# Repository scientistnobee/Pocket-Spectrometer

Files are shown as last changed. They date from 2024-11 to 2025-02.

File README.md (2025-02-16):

# Pocket Spectrometer

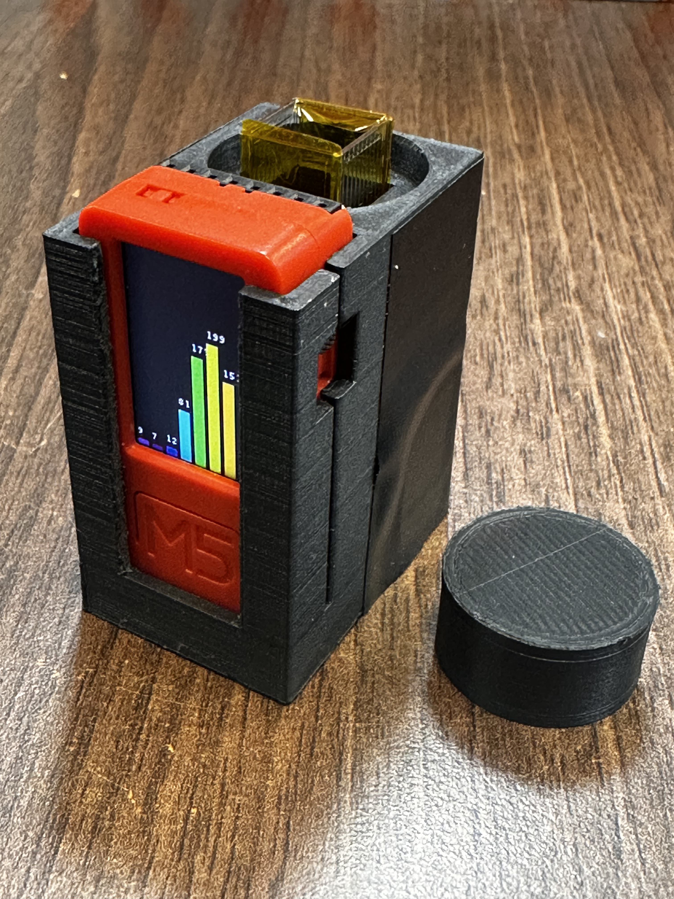
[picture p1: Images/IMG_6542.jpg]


## The Vision

I've always wanted to create a spectrometer that is so small it can fit into one's pocket and just barely larger than a cuvette itself. Working with bulky commercial spectrometers in labs, I was wondering about applications of such a small spectrometer. That's when I discovered the perfect combination – the M5StickC microcontroller and the AS7341 spectral sensor. My goal was simple: create an ultra-compact spectrometer that anyone could use.

## Why This Matters

While commercial spectrometers offer high precision, they're often expensive, bulky, and require a computer connection. I wanted something different – a standalone device that could fit in your pocket, complete with its own display and interface, without requiring external equipment such as connection to a mobile app or a computer. The kind of tool that could democratize spectroscopy for educators, students, and citizen scientists.

## Bill of Materials (BOM)

* 1x M5StickC (https://docs.m5stack.com/en/core/m5stickc_plus) 
* 1x AS7341 spectral sensor  (https://www.dfrobot.com/product-2132.html)
* 1x Grove connector  (https://docs.m5stack.com/en/accessory/cable/grove_cable)
* 2x M2 screws  (https://eu.mouser.com/ProductDetail/Harwin/M80-2260000B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)
* 2x M2 heat-set inserts  (https://www.mouser.com/ProductDetail/SI/IUTFB-M2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)
* Black filament for 3D printing  
* White reflector (Optional)

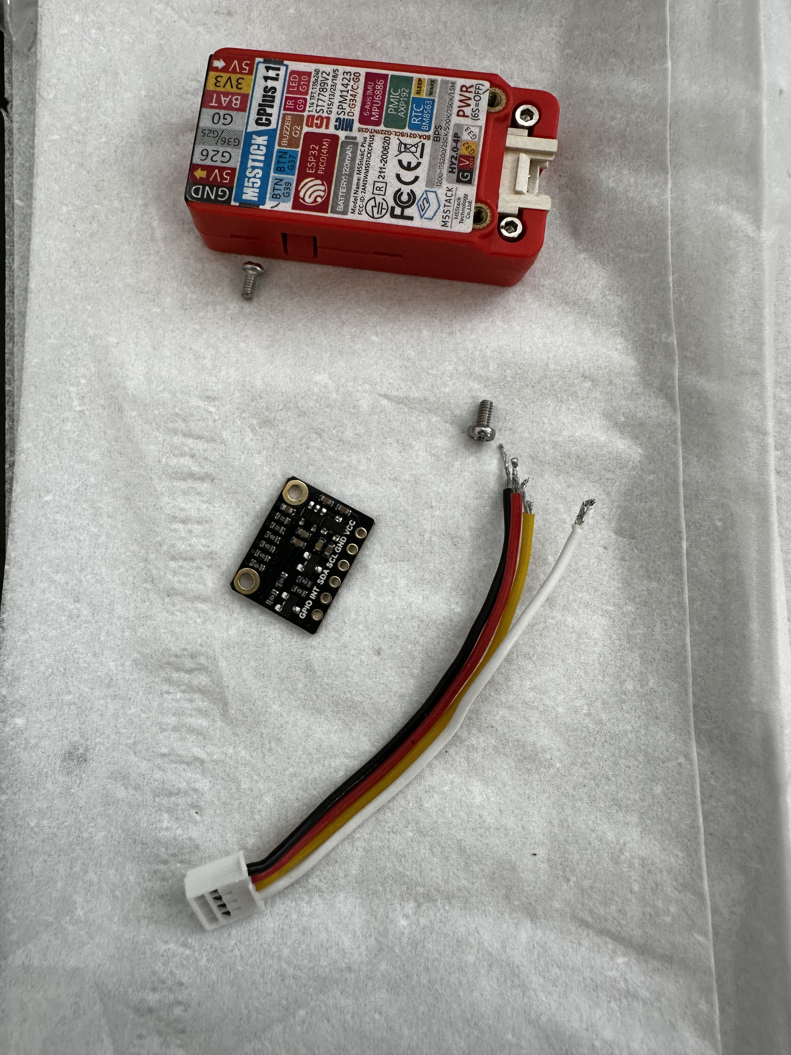
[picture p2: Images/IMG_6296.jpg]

## 3D-Printed Components

* Main body
* Cap

## Hardware Tools Required

* 3D printer  
* Soldering iron  
* Screwdriver

## Software Tools Required

* OpenSCAD for 3D printed parts (Optional, only required to modify the designs)  
* 3D printer slicer software (I used Ultimaker’s CURA)  
* Thonny IDE for programming

## Reasoning for choosing the particular Electronic Components

### AS7341 Spectral sensor: Advanced Spectral Sensing

The AS7341 sensor is crucial for this project:

* 11 readable individual sensor elements (10 light channels plus flicker detection)  
* Coverage from 350-1000 nm for comprehensive analysis  
* Built-in LED control for consistent illumination  
* Low power consumption for extended battery life  
* Affordable price point (\~$16)

### M5StickC: Portable but powerful mini computer

The M5StickC is the perfect platform for this project because it packs incredible functionality into a tiny package:

- Built-in rechargeable battery for true portability and for on-field applications  
- USB-C connector for easy charging and programming  
- Seeed Grove port for simple sensor connections  
- Two user-programmable buttons for interface control  
- TFT display screen for displaying spectra in real-time   
- Beautifully labeled breakout header for expansion  
- Extra in-bulit sensors (6-axis IMU, Microphone, IR transmitter)   
- Compact size (48.2 x 25.5 x 13.7mm) ideal for portable size of pocket spectrometer  
- MicroPython support for easy programming  
- Affordable price point (\~$20)

## Build Instructions

### Hardware Assembly

1. Cut the Grove connector to 15cm length and solder the wires  

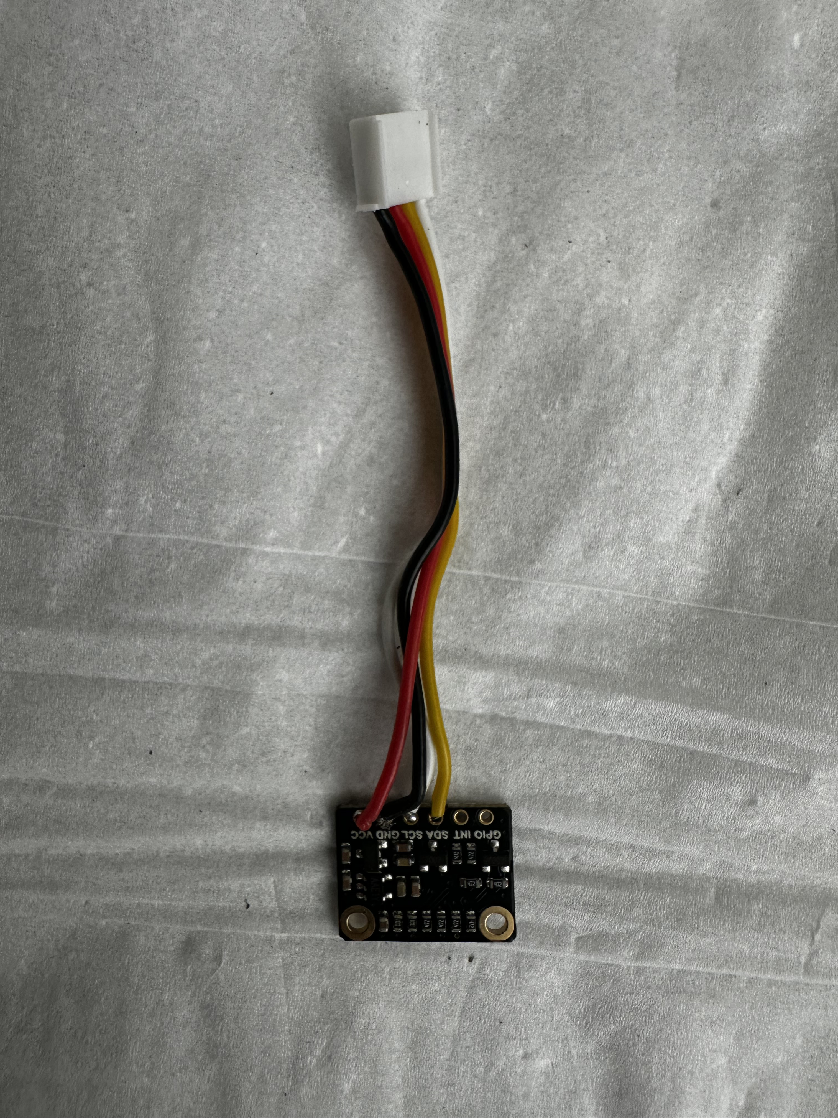
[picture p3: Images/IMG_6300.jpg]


3. Connect the Grove cable to the M5StickC  
4. Flash the firmware using Thonny  
5. Test the spectral sensor functionality  
6. Disconnect the Grove connector  
7. 3D print the main body and cap (no support required)  
8. Install M2 heat-set inserts using the soldering iron
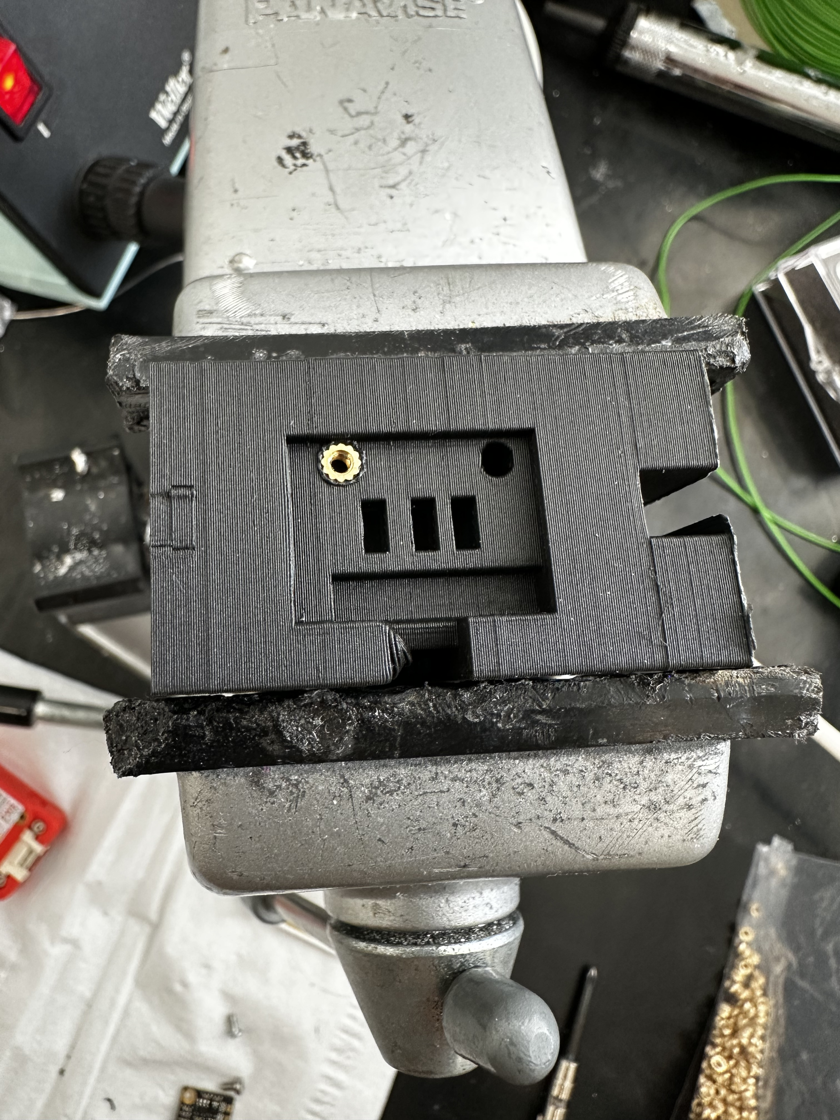
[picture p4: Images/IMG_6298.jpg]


9. Mount the AMS sensor to the body using M2 screws  
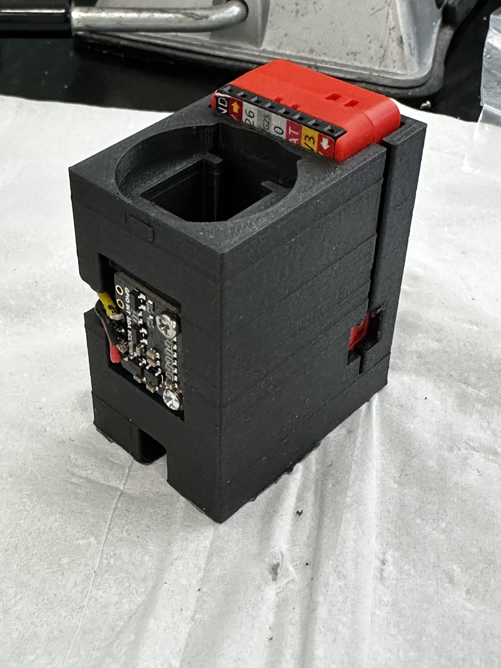
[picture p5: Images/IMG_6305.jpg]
    

10. Press-fit the M5StickC into the body from the top  
11. Connect the Grove connector from the bottom  
12. Apply black tape to cover the AMS sensor and wires


## Firmware Setup Instructions

### 1\. Prepare M5StickC

1. Power on the M5StickC  
2. Quickly press the M5 button after restart (using reset/PWR button) until you see the settings screen  
3. Select "Switch Mode" using the M5 button  
4. Choose "USB Mode" from the options

### 2\. Set Up Thonny IDE

1. Download and install [Thonny IDE](https://thonny.org/)  
2. Open Thonny  
3. Navigate to Tools \> Options \> Interpreter  
4. Configure settings:  
   - Set interpreter to "MicroPython (ESP32)"  
   - Select the correct COM port for your M5StickC  
   - Click OK and reconnect  
5. Once connected, you can write and test code directly in the IDE  
6. Best practice is to write your code in `main.py` for automatic execution on startup  

## Applications

The Pocket Spectrometer has numerous practical applications:

### Environmental Monitoring

* **Water Quality Testing**:  
  - Measure water turbidity  
  - Test chlorine content  
  - Monitor pH levels  
  - Assess water hardness  
  - Analyze phosphate content

### Biological Applications

* **Aquatic Habitat Monitoring**:  
  - Track ammonia levels  
  - Measure nitrate and nitrite concentrations  
  - Monitor phosphate levels  
  - Ideal for both freshwater and saltwater systems  
  - Perfect for aquaponics monitoring

### Environmental Testing

* **Soil Analysis**:  
  - Detect environmental pollutants  
  - Measure heavy metals like lead  
  - Test for oil contamination  
  - Monitor diesel presence  
  - Screen for pesticides

### Laboratory Use

* **Biochemical Analysis**:  
  - Protein quantification using Bradford assay  
  - Colorimetric enzyme assays  
  - Chemical concentration measurements  
  - Educational demonstrations  
  - STEM project applications

## Technical Implementation

The code is written in MicroPython for simplicity and accessibility, making it easy to modify for various applications. Most of the AI tools nowadays are good with python code, so would be handy to have the code in micropython.

## Future Work

* Upgrade to AS7343 as it has 14 spectral channels, compared to 10 spectral channels of  AS7341  
* Optimize battery life for extended field use  
* Conduct comprehensive testing (Work in progress)  
* Write the protocols in detail and make standard curve plots  
* Add saving the spectra as a time-stamped text file 

## Troubleshooting Tips for software

* If code doesn't execute properly, use the stop/rerun button in Thonny until you see three forward-looking arrows in the console  
* Restart the device if experiencing connection issues  
* Ensure proper USB mode selection before programming  
* Double-check Grove connector wiring if sensor readings are incorrect

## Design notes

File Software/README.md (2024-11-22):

# micropython-as7341

@Chinna Devarapu
- Adapted for M5StickC using bottom I2C sensor port
- Added LED control support for DF Robots AS7341 sensor
- Added example for saving spectral data as text (save_data.py)
- Main functionality in main.py: displays spectral data as bar graph with count values above bars
- Developed using Thonny IDE

Original MicroPython driver by Rob Hamerling (Version 0.0, September 2022)
- Class for AS7341: 11 Channel Multi-Spectral Digital Sensor
- Adapted from WaveShare's Raspberry Pi implementation
- Source: https://www.waveshare.com/w/upload/b/b3/AS7341_Spectral_Color_Sensor_code.7z

## Modifications from Original
- Required specification of active I2C interface
- Pythonized implementation
- Optimized function names and I2C communications
- Improved code readability
- Added documentation strings

## Getting Started
- Use Micropython device with hardware I2C (e.g. ESP32)
- Connect AS7341 board via I2C interface
- Copy required files:
  - as7341.py
  - as7341_smux_select.py
- For GPIO examples: Connect GPIO pin to +3.3V (10K resistor) and pushbutton to GND

## Examples
- all_channels.py: read whole range of channels
- flicker.py: read flicker
- gpio_in_en.py: show use of GPIO pin for input
- interrupt.py: use of interrupt pin
- led_blink_pwm: show control of onboard LED
- pinint.py: use pin to trigger read-out
- syns.py: syns-mode, measurement starts with GPIO transition

## Documentation
- AS7341_AN000666_1-01.pdf - Application Note: SMUX Configuration
- AS7341_DS000504_3-00.pdf - Datasheet: 11-Channel Multi-Spectral Digital Sensor

Note: Repository is work in progress.

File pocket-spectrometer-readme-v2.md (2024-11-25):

# Pocket Spectrometer Project

## The Vision

I've always wanted to create a spectrometer that is so small it can fit into one's pocket and just barely larger than a cuvette itself. Working with bulky commercial spectrometers in labs, I was wondering about applications of such a small spectrometer. That's when I discovered the perfect combination – the M5StickC microcontroller and the AS7341 spectral sensor. My goal was simple: create an ultra-compact spectrometer that anyone could use.

## Why This Matters

While commercial spectrometers offer high precision, they're often expensive, bulky, and require a computer connection. I wanted something different – a standalone device that could fit in your pocket, complete with its own display and interface, without requiring external equipment such as connection to a mobile app or a computer. The kind of tool that could democratize spectroscopy for educators, students, and citizen scientists.

## Bill of Materials (BOM)

* 1x M5StickC  
* 1x AS7341 spectral sensor  
* 1x Grove connector  
* 2x M2 screws  
* 2x M2 heat-set inserts  
* Black filament for 3D printing  
* White reflector (Optional)

## 3D-Printed Components

* Main body  
* Cap

## Hardware Tools Required

* 3D printer  
* Soldering iron  
* Screwdriver

## Software Tools Required

* OpenSCAD for 3D printed parts (Optional, only required to modify the designs)  
* 3D printer slicer software (I used Ultimaker’s CURA)  
* Thonny IDE for programming

## Reasoning for choosing the particular Electronic Components

### AS7341 Spectral sensor: Advanced Spectral Sensing

The AS7341 sensor is crucial for this project:

* 11 readable individual sensor elements (10 light channels plus flicker detection)  
* Coverage from 350-1000 nm for comprehensive analysis  
* Built-in LED control for consistent illumination  
* Low power consumption for extended battery life  
* Affordable price point (\~$16)

### M5StickC: Portable but powerful mini computer

The M5StickC is the perfect platform for this project because it packs incredible functionality into a tiny package:

- Built-in rechargeable battery for true portability and for on-field applications  
- USB-C connector for easy charging and programming  
- Seeed Grove port for simple sensor connections  
- Two user-programmable buttons for interface control  
- TFT display screen for displaying spectra in real-time   
- Beautifully labeled breakout header for expansion  
- Extra in-bulit sensors (6-axis IMU, Microphone, IR transmitter)   
- Compact size (48.2 x 25.5 x 13.7mm) ideal for portable size of pocket spectrometer  
- MicroPython support for easy programming  
- Affordable price point (\~$20)

## Build Instructions

### Hardware Assembly

1. Cut the Grove connector to 15cm length and solder the wires  
2. Connect the Grove cable to the M5StickC  
3. Flash the firmware using Thonny  
4. Test the spectral sensor functionality  
5. Disconnect the Grove connector  
6. 3D print the main body and cap (no support required)  
7. Install M2 heat-set inserts using the soldering iron  
8. Mount the AMS sensor to the body using M2 screws  
9. Press-fit the M5StickC into the body from the top  
10. Connect the Grove connector from the bottom  
11. Apply black tape to cover the AMS sensor and wires

## Firmware Setup Instructions

### 1\. Prepare M5StickC

1. Power on the M5StickC  
2. Quickly press the M5 button after restart (using reset/PWR button) until you see the settings screen  
3. Select "Switch Mode" using the M5 button  
4. Choose "USB Mode" from the options

### 2\. Set Up Thonny IDE

1. Download and install [Thonny IDE](https://thonny.org/)  
2. Open Thonny  
3. Navigate to Tools \> Options \> Interpreter  
4. Configure settings:  
   - Set interpreter to "MicroPython (ESP32)"  
   - Select the correct COM port for your M5StickC  
   - Click OK and reconnect  
5. Once connected, you can write and test code directly in the IDE  
6. Best practice is to write your code in `main.py` for automatic execution on startup  

## Applications

The Pocket Spectrometer has numerous practical applications:

### Environmental Monitoring

* **Water Quality Testing**:  
  - Measure water turbidity  
  - Test chlorine content  
  - Monitor pH levels  
  - Assess water hardness  
  - Analyze phosphate content

### Biological Applications

* **Aquatic Habitat Monitoring**:  
  - Track ammonia levels  
  - Measure nitrate and nitrite concentrations  
  - Monitor phosphate levels  
  - Ideal for both freshwater and saltwater systems  
  - Perfect for aquaponics monitoring

### Environmental Testing

* **Soil Analysis**:  
  - Detect environmental pollutants  
  - Measure heavy metals like lead  
  - Test for oil contamination  
  - Monitor diesel presence  
  - Screen for pesticides

### Laboratory Use

* **Biochemical Analysis**:  
  - Protein quantification using Bradford assay  
  - Colorimetric enzyme assays  
  - Chemical concentration measurements  
  - Educational demonstrations  
  - STEM project applications

## Technical Implementation

The code is written in MicroPython for simplicity and accessibility, making it easy to modify for various applications. Most of the AI tools nowadays are good with python code, so would be handy to have the code in micropython.

## Future Work

* Upgrade to AS7343 as it has 14 spectral channels, compared to 10 spectral channels of  AS7341  
* Optimize battery life for extended field use  
* Conduct comprehensive testing (Work in progress)  
* Write the protocols in detail and make standard curve plots  
* Add saving the spectra as a time-stamped text file 

## Troubleshooting Tips for software

* If code doesn't execute properly, use the stop/rerun button in Thonny until you see three forward-looking arrows in the console  
* Restart the device if experiencing connection issues  
* Ensure proper USB mode selection before programming  
* Double-check Grove connector wiring if sensor readings are incorrect

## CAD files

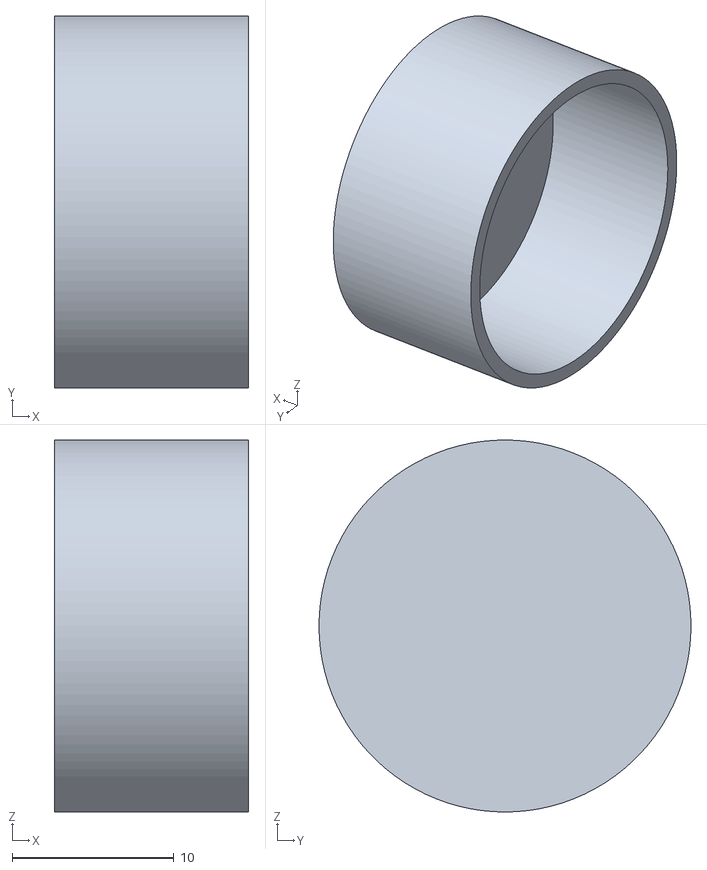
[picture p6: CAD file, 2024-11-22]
3D Design Files/STLs/Cap.stl
12.0 x 23.0 x 23.0

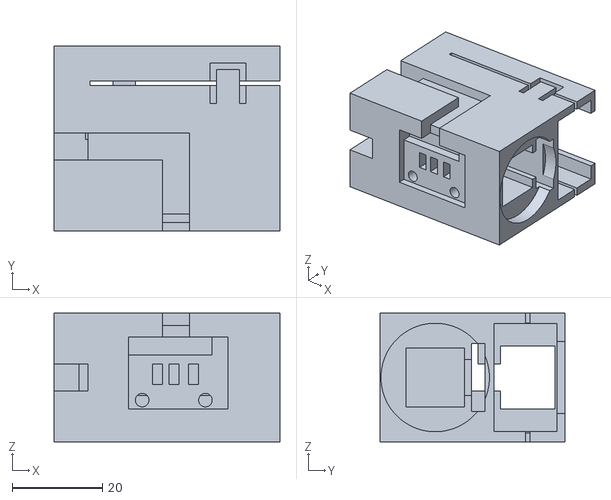
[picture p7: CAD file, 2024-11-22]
3D Design Files/STLs/Body.stl
50.0 x 41.0 x 28.5

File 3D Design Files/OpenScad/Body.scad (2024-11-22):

height_pd1=12;
height_pd=12;
 
$fn = 100; 
 w_m5=26.0;// width of m5stick
 h_m5=45;// height of m5stick
 t_m5=16; // thickness of m5stick
 wall=1.5; //wall of the body
 tol=0.5; //tolerance for printing
 
 difference(){
 union() {

     
      translate([0,0,0]) 
     cube ([h_m5,w_m5+tol+3,w_m5+tol+2], center=true);  //cuvette holder
     
           translate([-5,0,0]) 
     cube ([h_m5,w_m5+tol+3,w_m5+tol+2], center=true);  // extra cuvette holder bottom
     
     
       translate([0,18,0]) 
       cube ([h_m5, t_m5+tol, w_m5+tol+2], center=true);
     
            translate([-5,18,0]) 
       cube ([h_m5, t_m5+tol, w_m5+tol+2], center=true); //extra bottom part
     
     
      

 
     
 }
 union() {
      

         
          translate([21.0,-2.5,0])
     rotate([0,90,0])
     cylinder(d=24, h=4, center=true);// space for cap
     
  translate([-10,-14.8,-7])
rotate([90,0,0])
ams2();   //space for AMS spectral sensor
     
           translate([-24.0,4,8]) 
            cube ([8, 6, 13], center=true);// for wiring4
    
             translate([-14.0,4,13]) 
            cube ([22, 6, 3], center=true);// for wiring3

      
                  translate([-0.5,-14,10]) 
            cube ([6, 6, 3], center=true);// for wiring3c
     
            translate([-0.5,-4,13]) 
            cube ([6, 22, 3], center=true);// for wiring2
     
           translate([-24.0,4,0]) 
            cube ([8, 40, 6], center=true);// for wiring1 bottom
     
     translate([4,-2.5,0]) 
          cube ([h_m5+tol,13.0,13.0], center=true); //cuvette
            color([1,0,0.5])
        translate([0.5,17.5,0]) 
            cube ([ h_m5, t_m5-wall-0.5, w_m5-wall-0.5], center=true);//m5stickc
            
translate([11.0,18,13]) 
cube ([8, 9, 3], center=true);// for m5 buttonB

 
 
 translate([-12,18,-13]) 
cube ([8, 9, 3], center=true);// for m5 buttonC
 
 
  translate([3,18,-13]) 
cube ([h_m5, 1, 3], center=true);// for m5 slit1


translate([3,18,13]) 
cube ([h_m5, 1, 3], center=true);// for m5 slit2
 
               color([0.5,0,0.5])
        translate([-20,18,0]) 
           cube ([20,12,14], center=true); 
     
        translate([3,28,0]) 
           cube([44,10,16], center=true);//oled screen
     
             translate([2,7,0]) 
     cube ([45,3,15], center=true);  //optical_filter
     
     
             translate([5,3,0]) 
           cube([40,8,8], center=true);//optical sensor window 
   
 }
 }


module buttons(){
 translate([-12,19,-13.25]) 
cube ([5, 8, 2], center=true);// button for m5 buttonC
 
 
 translate([11.0,16.5,13.15]) 
cube ([5, 9, 2.2], center=true);// for m5 buttonB
}

module ams1(){

union(){
    translate([0,0,-1])
cube ([22.5,20.5,2.0]);  // PCB


color([0.4,0.6,0.1])
translate([3.4,3,-2.0])
union(){
translate([0,0,0])
cylinder(d=2.9, h=10);//screw hole1

translate([15.1,0,0])
cylinder(d=2.9, h=10);//screw hole2
}
}
union(){


color([0.4,0.6,0.5])

translate([0,8.5,-2.5])
union(){
    
    translate([10-0.1,0,0])
cube ([2.2,3.5,4]); //Ams sensor
translate([6.1,0,0])    
cube ([1.5,3.5,4]); //LED1
    translate([14.1,0,0])    
cube ([1.5,3.5,4]); //LED2
    
}
}


}

module ams2(){

union(){
       translate([-1,0,-2])
cube ([22,16,5.0]);  // PCB

       translate([-1.0,12,-4.5])
cube ([18.5,4,3.0]);  // PCB holes 


}
union(){

    
color([0.4,0.6,0.1])
translate([2,2,-4.0])
union(){
translate([0,0,-2])
cylinder(d=3, h=10);//screw hole1

translate([14,0,-2])
cylinder(d=3, h=10);//screw hole2
}
color([0.4,0.6,0.5])

translate([0,5.5,-4.5])
union(){
    
    translate([8-0.1,0,-2])
cube ([2.3,4.5,10]); //Ams sensor
translate([4.3,0,-2])    
cube ([2.2,4.5,10]); //LED1
    translate([12.3,0,-2])    
cube ([2.2,4.5,10]); //LED2
    
}
}
}






 module cap(){
difference(){
 union() {
 rotate([0,90,0])
         translate([0,0,0])
     cylinder(d=23.5, h=12, center=true);
     
 }

 union() {
              translate([-0.1,0.0,0.0])
 rotate([0,90,0])

     cylinder(d=20, h=12, center=true);
     }
 
 }
 }
 
//translate([30,-3,0])
//cap();
 
  //translate([-10,-12,-7])
//rotate([90,0,0])
//ams2();
 
 buttons();

     

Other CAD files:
3D Design Files/OpenScad/Cap.scad

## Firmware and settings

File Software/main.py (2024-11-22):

import display
from machine import I2C, Pin
from time import sleep_ms
from as7341 import *  # Import the AS7341 sensor library
from m5stack import btnA  # Import the button

# Initialize I2C and AS7341 sensor
i2c = I2C(sda=Pin(32), scl=Pin(33))

sensor = AS7341(i2c)
if not sensor.isconnected():
    print("Failed to contact AS7341, terminating")
    sys.exit(1)

sensor.set_measure_mode(AS7341_MODE_SPM)
sensor.set_atime(29)                # 30 ASTEPS
sensor.set_astep(599)               # 1.67 ms
sensor.set_again(4)                 # factor 8 (with pretty much light)

# LED control functions
def set_led_current(current_mA):
    """Set the LED current in mA (range: 0 to 100 mA)."""
    sensor.set_led_current(current_mA)

def enable_led(enable):
    """Enable or disable the onboard LED."""
    sensor.enable_led(enable)

# Create the TFT display object
tft = display.TFT()

# Define custom colors
PURPLE = 0x800080
VIOLET = 0x9400D3

# Function to display the spectral data as a bar graph
def display_spectrum(f1, f2, f3, f4, f5, f6, f7, f8):
    tft.clear(tft.BLACK)

    # Scale the values to fit on the screen
    max_val = max(f1, f2, f3, f4, f5, f6, f7, f8)
    scale = 150 / max_val if max_val > 0 else 1

    # Adjust the bar width and spacing to fit the screen
    bar_width = 12
    spacing = 5
    start_x = (135 - (8 * bar_width + 7 * spacing)) // 2

    bars = [f1, f2, f3, f4, f5, f6, f7, f8]
    colors = [VIOLET, PURPLE, tft.BLUE, tft.CYAN, tft.GREEN, tft.YELLOW, tft.ORANGE, tft.RED]

    for i, bar in enumerate(bars):
        height = int(bar * scale)
        color = colors[i]
        tft.rect(start_x + i * (bar_width + spacing), 240 - height, bar_width, height, color, color)
        tft.font(tft.FONT_DefaultSmall)
        tft.text(start_x + i * (bar_width + spacing), 240 - height - 15, str(bar), tft.WHITE)

try:
    while True:
        if btnA.wasPressed():  # Check if the button is pressed
            print("Turning on LED")
            set_led_current(25)  # Set LED current to 25mA
            enable_led(True)

            # Perform spectral measurement
            sensor.start_measure("F1F4CN")
            f1, f2, f3, f4, clr, nir = sensor.get_spectral_data()
            sensor.start_measure("F5F8CN")
            f5, f6, f7, f8, clr, nir = sensor.get_spectral_data()

            display_spectrum(f1, f2, f3, f4, f5, f6, f7, f8)

            print("Turning off LED")
            enable_led(False)  # Turn off the LED after measurement
        sleep_ms(100)

except KeyboardInterrupt:
    print("Interrupted from keyboard")

sensor.disable()

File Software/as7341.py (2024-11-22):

"""
This file licensed under the MIT License and incorporates work covered by
the following copyright and permission notice:

The MIT License (MIT)

Copyright (c) 2022-2022 Rob Hamerling

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
Rob Hamerling, Version 0.0, October 2022

 Original by WaveShare for Raspberry Pi, part of:
    https://www.waveshare.com/w/upload/b/b3/AS7341_Spectral_Color_Sensor_code.7z

 Converted to Micropython for use with MicroPython devices such as ESP32
    - pythonized (in stead of 'literal' translation of C code)
    - instance of AS7341 requires specification of I2C interface
    - added I2C read/write error detection
    - added check for connected AS7341 incl. device ID
    - some code optimization (esp. adding I2C word/block reads/writes)
    - Replaced bit addressing like (1<<5) by symbolic name with bit mask
    - moved SMUX settings for predefined channel mappings to a dictionary
      and as a separate file to allow changes or additional configurations
      by the user without changing the driver
    - several changes of names of functions and constants
      (incl. camel case -> word separators with underscores)
    - added comments, doc-strings with explanation and/or argumentation
    - several other improvements and some corrections

  Remarks:
    - Automatic Gain Control (AGC) is not supported
    - No provisions for SYND mode

"""

from time import sleep_ms

from as7341_smux_select import *            # predefined SMUX configurations

AS7341_I2C_ADDRESS  = const(0x39)           # I2C address of AS7341
AS7341_ID_VALUE     = const(0x24)           # AS7341 Part Number Identification
                                            # (excl 2 low order bits)

# Symbolic names for registers and some selected bit fields
# Note: ASTATUS, ITIME and CHx_DATA in address range 0x60--0x6F are not used
AS7341_CONFIG       = const(0x70)
AS7341_CONFIG_INT_MODE_SPM  = const(0x00)
AS7341_MODE_SPM             = AS7341_CONFIG_INT_MODE_SPM    # alias
AS7341_CONFIG_INT_MODE_SYNS = const(0x01)
AS7341_MODE_SYNS            = AS7341_CONFIG_INT_MODE_SYNS   # alias
AS7341_CONFIG_INT_MODE_SYND = const(0x03)
AS7341_MODE_SYND            = AS7341_CONFIG_INT_MODE_SYND   # alias
AS7341_CONFIG_INT_SEL       = const(0x04)
AS7341_CONFIG_LED_SEL       = const(0x08)
AS7341_STAT         = const(0x71)
AS7341_STAT_READY     = const(0x01)
AS7341_STAT_WAIT_SYNC = const(0x02)
AS7341_EDGE         = const(0x72)
AS7341_GPIO         = const(0x73)
AS7341_GPIO_PD_INT    = const(0x01)
AS7341_GPIO_PD_GPIO   = const(0x02)
AS7341_LED          = const(0x74)
AS7341_LED_LED_ACT    = const(0x80)
AS7341_ENABLE       = const(0x80)
AS7341_ENABLE_PON     = const(0x01)
AS7341_ENABLE_SP_EN   = const(0x02)
AS7341_ENABLE_WEN     = const(0x08)
AS7341_ENABLE_SMUXEN  = const(0x10)
AS7341_ENABLE_FDEN    = const(0x40)
AS7341_ATIME        = const(0x81)
AS7341_WTIME        = const(0x83)
AS7341_SP_TH_LOW    = const(0x84)
AS7341_SP_TH_L_LSB  = const(0x84)
AS7341_SP_TH_L_MSB  = const(0x85)
AS7341_SP_TH_HIGH   = const(0x86)
AS7341_SP_TH_H_LSB  = const(0x86)
AS7341_SP_TH_H_MSB  = const(0x87)
AS7341_AUXID        = const(0x90)
AS7341_REVID        = const(0x91)
AS7341_ID           = const(0x92)
AS7341_STATUS       = const(0x93)
AS7341_STATUS_ASAT    = const(0x80)
AS7341_STATUS_AINT    = const(0x08)
AS7341_STATUS_FINT    = const(0x04)
AS7341_STATUS_C_INT   = const(0x02)
AS7341_STATUS_SINT    = const(0x01)
AS7341_ASTATUS      = const(0x94)       # start of bulk read (incl 6 counts)
AS7341_ASTATUS_ASAT_STATUS  = const(0x80)
AS7341_ASTATUS_AGAIN_STATUS = const(0x0F)
AS7341_CH_DATA      = const(0x95)       # start of the 6 channel counts
AS7341_CH0_DATA_L   = const(0x95)
AS7341_CH0_DATA_H   = const(0x96)
AS7341_CH1_DATA_L   = const(0x97)
AS7341_CH1_DATA_H   = const(0x98)
AS7341_CH2_DATA_L   = const(0x99)
AS7341_CH2_DATA_H   = const(0x9A)
AS7341_CH3_DATA_L   = const(0x9B)
AS7341_CH3_DATA_H   = const(0x9C)
AS7341_CH4_DATA_L   = const(0x9D)
AS7341_CH4_DATA_H   = const(0x9E)
AS7341_CH5_DATA_L   = const(0x9F)
AS7341_CH5_DATA_H   = const(0xA0)
AS7341_STATUS_2     = const(0xA3)
AS7341_STATUS_2_AVALID = const(0x40)
AS7341_STATUS_3     = const(0xA4)
AS7341_STATUS_5     = const(0xA6)
AS7341_STATUS_6     = const(0xA7)
AS7341_CFG_0        = const(0xA9)
AS7341_CFG_0_WLONG     = const(0x04)
AS7341_CFG_0_REG_BANK  = const(0x10)        # datasheet fig 82 (! fig 32)
AS7341_CFG_0_LOW_POWER = const(0x20)
AS7341_CFG_1        = const(0xAA)
AS7341_CFG_3        = const(0xAC)
AS7341_CFG_6        = const(0xAF)
AS7341_CFG_6_SMUX_CMD_ROM   = const(0x00)
AS7341_CFG_6_SMUX_CMD_READ  = const(0x08)
AS7341_CFG_6_SMUX_CMD_WRITE = const(0x10)
AS7341_CFG_8        = const(0xB1)
AS7341_CFG_9        = const(0xB2)
AS7341_CFG_10       = const(0xB3)
AS7341_CFG_12       = const(0xB5)
AS7341_PERS         = const(0xBD)
AS7341_GPIO_2       = const(0xBE)
AS7341_GPIO_2_GPIO_IN    = const(0x01)
AS7341_GPIO_2_GPIO_OUT   = const(0x02)
AS7341_GPIO_2_GPIO_IN_EN = const(0x04)
AS7341_GPIO_2_GPIO_INV   = const(0x08)
AS7341_ASTEP        = const(0xCA)
AS7341_ASTEP_L      = const(0xCA)
AS7341_ASTEP_H      = const(0xCB)
AS7341_AGC_GAIN_MAX = const(0xCF)
AS7341_AZ_CONFIG    = const(0xD6)
AS7341_FD_TIME_1    = const(0xD8)
AS7341_FD_TIME_2    = const(0xDA)
AS7341_FD_CFG0      = const(0xD7)
AS7341_FD_STATUS    = const(0xDB)
AS7341_FD_STATUS_FD_100HZ      = const(0x01)
AS7341_FD_STATUS_FD_120HZ      = const(0x02)
AS7341_FD_STATUS_FD_100_VALID  = const(0x04)
AS7341_FD_STATUS_FD_120_VALID  = const(0x08)
AS7341_FD_STATUS_FD_SAT_DETECT = const(0x10)
AS7341_FD_STATUS_FD_MEAS_VALID = const(0x20)
AS7341_INTENAB      = const(0xF9)
AS7341_INTENAB_SP_IEN = const(0x08)
AS7341_CONTROL      = const(0xFA)
AS7341_FIFO_MAP     = const(0xFC)
AS7341_FIFO_LVL     = const(0xFD)
AS7341_FDATA        = const(0xFE)
AS7341_FDATA_L      = const(0xFE)
AS7341_FDATA_H      = const(0xFF)
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
